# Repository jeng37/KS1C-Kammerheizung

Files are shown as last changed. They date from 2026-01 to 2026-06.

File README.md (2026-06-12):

# KS1C – Kammerheizung (ESPHome + Home Assistant)
Visitor Count

⚠️ <span style="color:red"><strong>WICHTIG – DIY-PROJEKT!</strong></span>  
<span style="color:red">
Dieses Projekt ist ein reines DIY-Projekt.  
Der Nachbau erfolgt **auf eigene Gefahr**.  
Ich übernehme **keinerlei Haftung** für Schäden an Personen, Geräten oder Eigentum.
</span>

⚠️ <span style="color:red"><strong>DRUCKMATERIAL:</strong></span>  
<span style="color:red">
Alle 3D-gedruckten Teile **MÜSSEN aus ASA** (oder gleichwertig hitzebeständigem Material) gedruckt werden.  
PLA, PETG oder ABS sind **nicht geeignet**!
</span>

---

🔥 **ESP32-basierte Kammerheizung für geschlossene 3D-Drucker**  
Mit automatischer Temperaturregelung, Sicherheitsfunktionen, Display  
und direkter Integration in **Home Assistant** und **Moonraker**.

---

## 📸 Projektbilder

### Dashboard
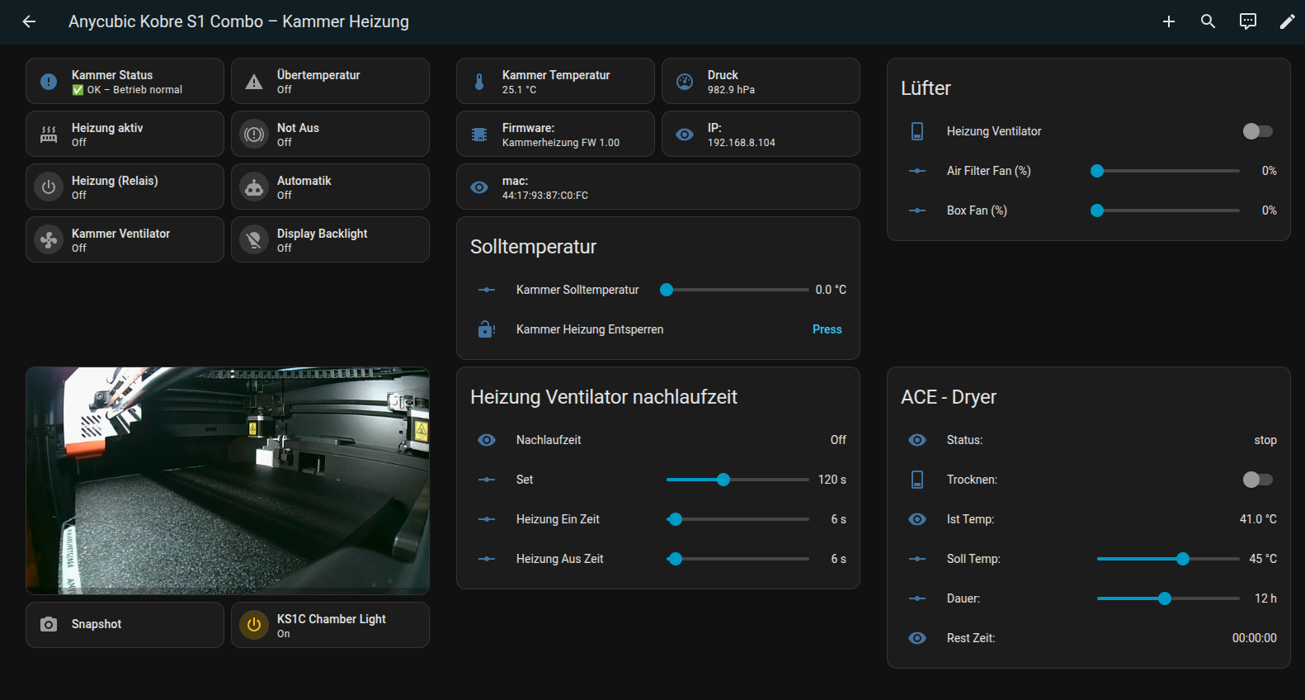
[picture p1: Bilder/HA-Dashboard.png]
Dashboard


---

## ✨ Features

- ESP32 (TTGO T-Display) mit integriertem TFT-Display
- Temperaturregelung für geschlossene Druckkammern
- Zwei **Solid State Relais (SSR)** für:
  - Heizung (230 V)
  - Kammerlüfter (230 V)
- **Taktbetrieb** für überdimensionierte Heizungen
- Lüfter-Vorlauf & Nachlauf
- **Not-Aus**, Übertemperaturschutz & WLAN-Failsafe
- Native **ESPHome-Integration**
- **Moonraker-Anbindung** für MMU-Dryer-Status
- Vollständig lokal, kein Cloud-Zwang

---

## 🧠 Systemübersicht

Dieses Projekt ist strikt in **zwei Spannungsbereiche** getrennt:

| Bereich | Spannung | Beschreibung |
|---|---|---|
| Niederspannung | 3,3 V DC | ESP32, Sensoren, SSR-Eingänge |
| Netzspannung | 230 V AC | Heizung, Lüfter |

👉 Die Trennung erfolgt **ausschließlich über Solid State Relais**.

---

## 🧯 Sicherheitsfunktionen

- ❌ **Übertemperatur > 65 °C** → Sofortige Abschaltung
- 📡 **WLAN-Ausfall** → Hard-Shutdown + manuelle Entsperrung nötig
- 🛑 **Not-Aus** → Heizung AUS, Lüfter EIN
- 🌀 **Lüfter-Nachlauf** nach Heizende

---

## ⚠️ Wichtiger Hinweis

Dieses Projekt arbeitet mit **230 V Netzspannung**.  
Falsche Verdrahtung kann **lebensgefährlich** sein.

> ❗ Nachbau nur, wenn du weißt, was du tust.  
> ❗ Immer Sicherungen, Erdung und geschlossenes Gehäuse verwenden.

---

## 📄 Lizenz

Dieses Projekt ist für private Nutzung gedacht.  
Siehe `LICENSE` Datei für Details.

---

## Credits

Projekt & Umsetzung: **jeng37**  
ESPHome • Home Assistant • Moonraker Community

---

## 🕹️ Live bOX BBS

Want to see this project in action? Connect to my live old-school **PCBoard bOX BBS** over SSH.

```text
Host:     mybbs.duckdns.org
Port:     2222
Protocol: SSH
Login:    bbs
Password: bbs
```

Example:

```bash
ssh bbs@mybbs.duckdns.org -p 2222
```

For the best ANSI/PCBoard experience, use the preconfigured SyncTERM package included in this repository:

```text
syncterm/syncterm_v1.9.rc3_bOX_ALL_BUILDS.zip
```

Included builds:

```text
Win_x86
Win_x64
Linux_x86
Linux_x64
```

The SyncTERM package is already configured for the bOX BBS. You can also connect with any ANSI-capable terminal such as SyncTERM, ZOC, NetRunner, PuTTY, or another classic Telnet/ANSI client.

> Nostalgia mode: real old-school PCBoard BBS experience.

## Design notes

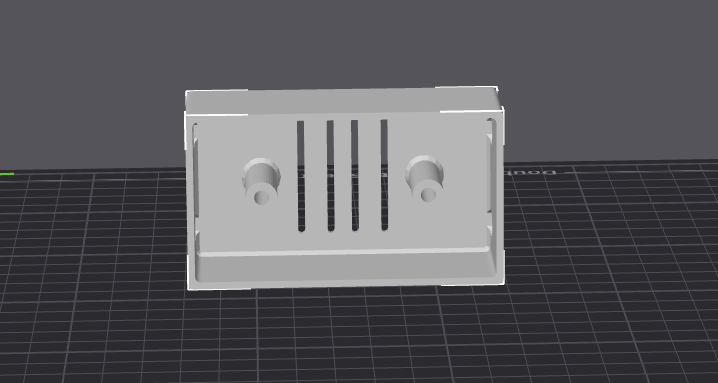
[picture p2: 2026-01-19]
Bilder/SSR.png

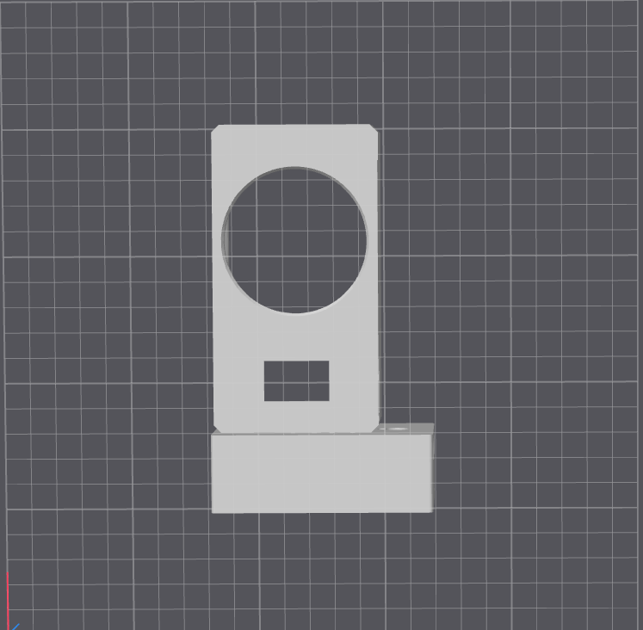
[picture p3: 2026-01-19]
Bilder/Kammer-Heizung-Box1.png

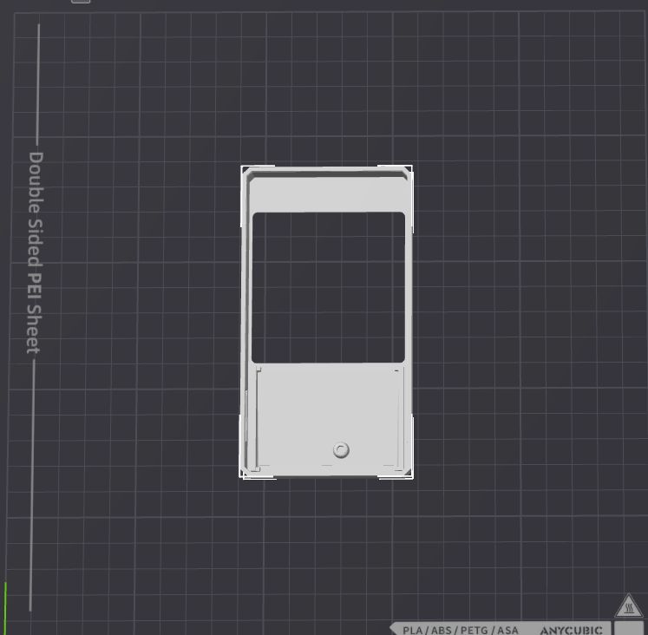
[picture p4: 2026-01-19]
Bilder/Kammer-Heizung-Front.png

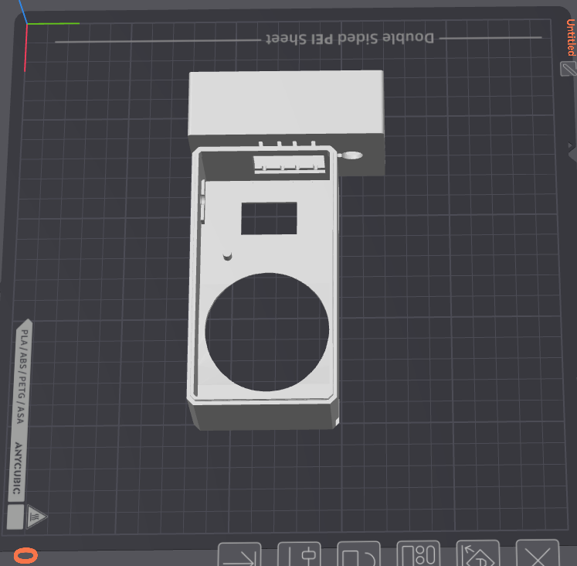
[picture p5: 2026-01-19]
Bilder/Kammer-Heizung-Box2.png

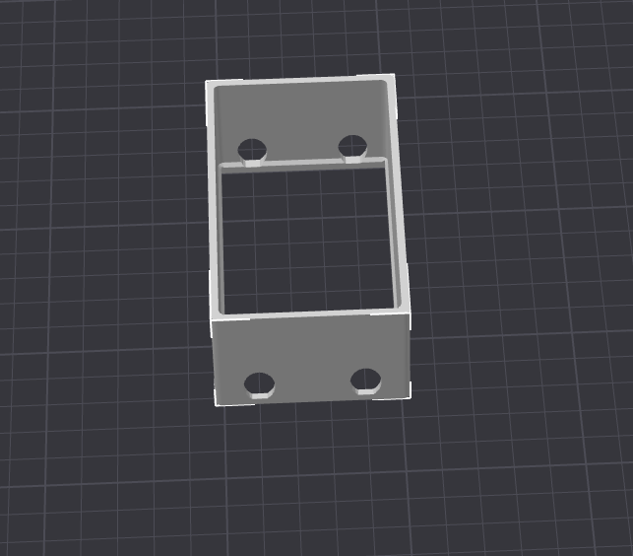
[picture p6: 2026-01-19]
Bilder/SSR verlänegrung.png

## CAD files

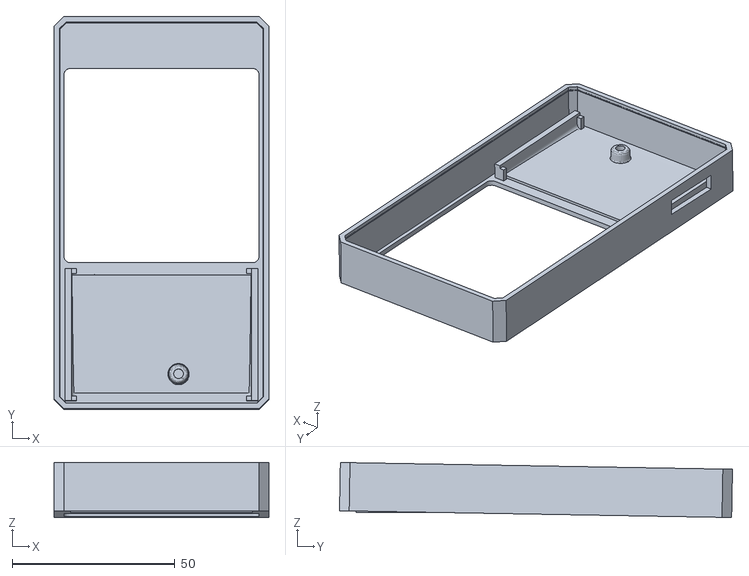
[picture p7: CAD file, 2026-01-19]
STL/Kammer-Heizung-Back.stl
66.0 x 120.6 x 16.9

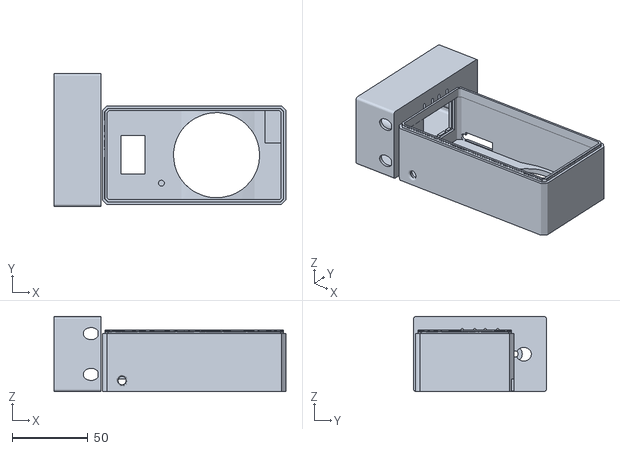
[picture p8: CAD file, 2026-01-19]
STL/Kammer-Heizung-Box.stl
153.7 x 88.0 x 49.7

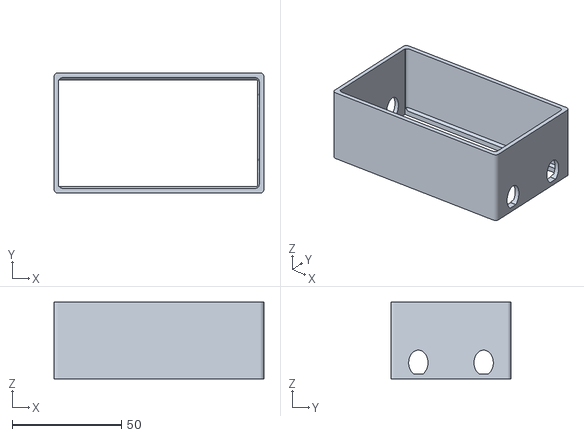
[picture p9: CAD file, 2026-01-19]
STL/SSR verlänegrung.stl
96.0 x 55.0 x 35.0

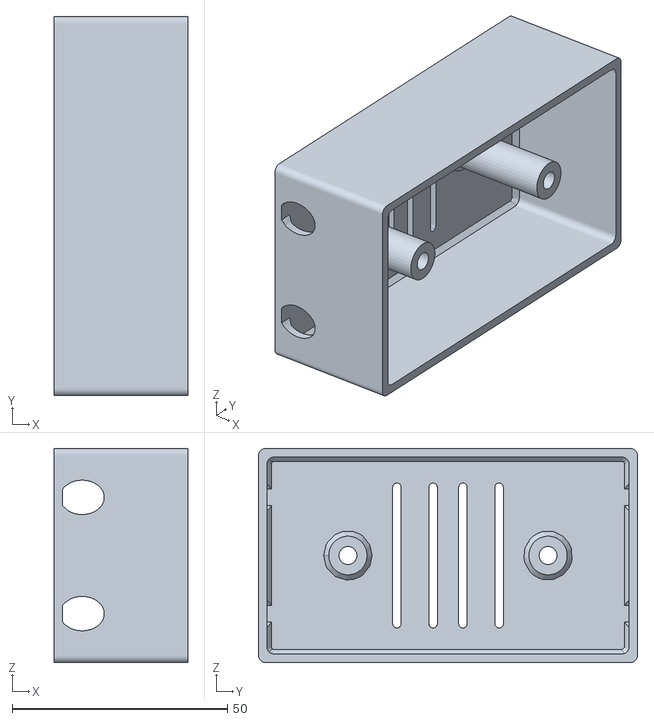
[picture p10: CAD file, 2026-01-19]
STL/SSR.stl
31.0 x 88.0 x 49.7

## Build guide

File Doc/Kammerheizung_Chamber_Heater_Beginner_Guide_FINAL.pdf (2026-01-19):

# Kammer-Heizung (Chamber Heater) – Complete Beginner Build Guide (EN)

This document is based exactly on the provided ESPHome configuration and the following Amazon hardware. It is written for beginners and clearly separates low-voltage (ESP32) and high-voltage (230V AC) wiring. Working with 230V AC is dangerous. If you are unsure, ask a qualified electrician.

## 1. Used Hardware (Exact Amazon Parts)

Role | Exact Product Name | Amazon Link
Controller | LILYGO TTGO T-Display ESP32 (CH9102F, ST7789) | https://www.amazon.de/dp/B099MPFJ9M
Solid State Relays (2x) | BGTXINGI SSR-40DA (DC 3–32V input / AC 24–380V output) | https://www.amazon.de/dp/B09NDFDLLN
Heater | PTC Heater 220V 300W with fan (self-regulating) | https://www.amazon.de/dp/B09XV41P7L

Important clarification:
- Both SSRs are identical BGTXINGI SSR-40DA modules.
- Each SSR has a DC control side (3–32V) and an AC load side (230V).
- One SSR switches the heater, the second SSR switches the chamber fan.

## 2. Safety Rules (READ FIRST)

- 230V AC can kill you.
- Always disconnect mains power before wiring.
- Use proper insulated terminals and strain relief.
- SSRs must be mounted on a metal surface for heat dissipation.
- Never touch the AC side while powered.

## 3. System Overview

The ESP32 controls two SSRs using low-voltage GPIO signals. The SSRs safely isolate the ESP32 from the 230V AC heater and fan.

## 4. ESP32 Pin Mapping (Low Voltage Side)

ESP32 Pin | Function | Connects To
GPIO25 | Heater control | SSR #1 DC input +
GPIO26 | Fan control | SSR #2 DC input +
GND | Common ground | SSR DC input − (both)
3.3V | Sensor power | BMP280 VCC
GPIO21 | I2C SDA | BMP280 SDA
GPIO22 | I2C SCL | BMP280 SCL

## 5. SSR Wiring (High Voltage Side – 230V AC)

SSR #1 – Heater:
- AC L (Phase) → SSR terminal 1
- SSR terminal 2 → Heater L input
- Heater N → directly to AC Neutral

SSR #2 – Fan:
- AC L (Phase) → SSR terminal 1
- SSR terminal 2 → Fan L input
- Fan N → directly to AC Neutral

NOTE: Neutral (N) is never switched. Only Phase (L) is switched by the SSRs.

## 6. First Power-On Checklist

✓ All AC wiring insulated and secured
✓ SSRs mounted on metal surface
✓ ESP32 powered via USB only (first test)
✓ Heater and fan disconnected for initial logic test
✓ ESPHome logs show correct temperature readings

Firmware version: Kammerheizung FW 1.00 (matches ESPHome substitutions)

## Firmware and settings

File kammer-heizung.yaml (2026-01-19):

esphome:
  name: kammerheizung
  friendly_name: "Kammer-Heizung"

  on_boot:
    priority: -100
    then:
      # ALLES AUS (hart)
      - switch.turn_off: heater
      - switch.turn_off: fan
      - switch.turn_off: automatik
      - light.turn_off: heater_led

      # Moonraker Fan auf 0
      - number.set:
          id: air_filter_fan_speed
          value: 0
      - number.set:
          id: box_fan_speed
          value: 0

      # Status / Timer / Sequenzen resetten (WLAN-Lock bleibt bestehen!)
      - lambda: |-
          id(fan_off_time) = 0;
          id(prestart_active) = false;
          id(prestart_end_time) = 0;
          id(pending_heater_on) = false;

          if (!id(wifi_lost_lock)) {
            id(notaus_active) = false;
            id(blocked) = false;
          }

substitutions:
  moonraker_ip: "192.168.8.140"
  moonraker_port: "7125"
  firmware_version: "1.00"

esp32:
  board: esp32dev
  framework:
    type: arduino

logger:
  level: DEBUG

api:
  encryption:
    key: "iu321vfh2YTcH8dSedgPP9i3Igz/OJUQzUQRm0vj+6g="
  on_client_disconnected:
    then:
      - switch.turn_off: heater
      - switch.turn_off: automatik
      - switch.turn_off: fan
      - light.turn_off: heater_led

ota:
  - platform: esphome
    password: "12345679"

wifi:
  ssid: !secret wifi_ssid2
  password: !secret wifi_password2
  fast_connect: false
  power_save_mode: none
  min_auth_mode: WPA
  reboot_timeout: 5min

  ap:
    ssid: "Kammer-Heizung-Fallback"
    password: "12345679"

  on_disconnect:
    then:
      - script.execute: wifi_emergency_shutdown

captive_portal:

web_server:
  port: 80
  version: 3
  auth:
    username: admin
    password: rootlu

http_request:
  useragent: esphome-kammerheizung
  timeout: 5s
  verify_ssl: false

globals:
  - id: fan_off_time
    type: uint32_t
    restore_value: no
    initial_value: '0'

  - id: notaus_active
    type: bool
    restore_value: no
    initial_value: 'false'

  - id: blocked
    type: bool
    restore_value: no
    initial_value: 'false'

  - id: wifi_lost_lock
    type: bool
    restore_value: no
    initial_value: 'false'

  # Vorlauf-State-Machine (non-blocking)
  - id: prestart_active
    type: bool
    restore_value: no
    initial_value: 'false'

  - id: prestart_end_time
    type: uint32_t
    restore_value: no
    initial_value: '0'

  - id: pending_heater_on
    type: bool
    restore_value: no
    initial_value: 'false'

  - id: heating_allowed
    type: bool
    restore_value: no
    initial_value: 'false'

  - id: heater_cycle_on
    type: bool
    restore_value: no
    initial_value: 'true'

  - id: heater_cycle_ts
    type: uint32_t
    restore_value: no
    initial_value: '0'

# =========================
# I2C (ESP32 vs ESP8266!)
#  orange GND (relay heizung - )
#  rot 25 - D5 (relay heizung + )
#  schwarz (relay ventilator - )
#  weiss 26 - D6 (relay ventilator + )  
#  Grün 3,3v bme280
#  Bau GND  bme280
#  Gelb 22 - D2  bme280
#  Orange 21 - D1 bme280
# =========================
i2c:
  sda: 21 # D2
  scl: 22 # D1
  scan: true

spi:
  clk_pin: 18
  mosi_pin: 19


display:
  - platform: st7789v
    model: "TTGO TDISPLAY 135x240"
    cs_pin: 5
    dc_pin: 16
    reset_pin: 23
    rotation: 90
    update_interval: 2s
    backlight_pin: false

    lambda: |-
      it.fill(Color(0, 0, 0));  // schwarz

      // 🔒 WLAN-SICHERHEITSMELDUNG (HAT ABSOLUTE PRIORITÄT)
      if (id(wifi_lost_lock)) {
        it.printf(120, 40, id(font_title), Color(255, 0, 0),
                  TextAlign::TOP_CENTER, "WLAN AUS!");
        it.printf(120, 80, id(font_label), Color(255, 255, 0),
                  TextAlign::TOP_CENTER, "SYSTEM GESPERRT");
        it.printf(120, 120, id(font_label), Color(180, 180, 180),
                  TextAlign::TOP_CENTER, "Manuell entsperren");
        return;
      }

      // ===== ÜBERSCHRIFT =====
      it.printf(120, 5, id(font_title), Color(255, 165, 0),
                TextAlign::TOP_CENTER, "Kammer Heizung");

      // ===== SOLL =====
      it.printf(10, 50, id(font_label), Color(0, 255, 255), "Soll:");
      it.printf(200, 50, id(font_value), Color(0, 255, 255),
                TextAlign::TOP_RIGHT, "%.1f C", id(target_temp).state);

      // ===== IST (farbig) =====
      Color ist_color = Color(0, 255, 0);  // grün
      if (id(chamber_temp).state < id(target_temp).state - 1.0) {
        ist_color = Color(0, 0, 255);   // blau
      } else if (id(chamber_temp).state > id(target_temp).state + 1.0) {
        ist_color = Color(255, 0, 0);   // rot
      }

      it.printf(10, 90, id(font_label), ist_color, "Ist:");
      it.printf(200, 90, id(font_big), ist_color,
                TextAlign::TOP_RIGHT, "%.1f C", id(chamber_temp).state);

font:
  - file: "fonts/Arial.ttf"
    id: font_title
    size: 24
  - file: "fonts/Arial.ttf"
    id: font_label
    size: 18
  - file: "fonts/Arial.ttf"
    id: font_value
    size: 18
  - file: "fonts/Arial.ttf"
    id: font_big
    size: 28
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
